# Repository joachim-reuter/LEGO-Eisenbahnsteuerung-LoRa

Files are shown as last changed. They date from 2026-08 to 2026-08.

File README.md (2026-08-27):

# LEGO-Eisenbahnsteuerung mit ESP32 und LoRa
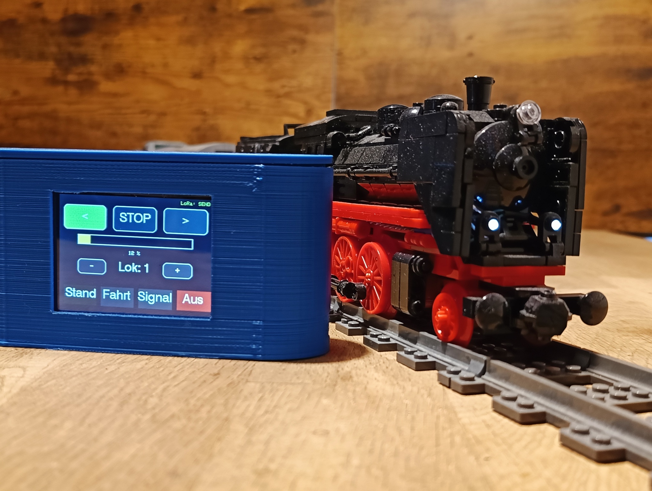
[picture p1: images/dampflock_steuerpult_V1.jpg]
LEGO-Eisenbahnanlage

Drahtlose Steuerung einer LEGO-Eisenbahn mit ESP32, LoRa, TFT-Touchdisplay, Motortreiber und Sound.

## Projektübersicht

                         LEGO-EISENBAHN
                               │
              ┌────────────────┴────────────────┐
              │                                 │
              ▼                                 ▼
       LOKSTEUERUNG                       WEICHENSTEUERUNG
              │                                 │
        TFT Touchdisplay                  TFT Touchdisplay
              │                                 │
              ▼                                 ▼
        LoRa Sender                        LoRa Sender
              │                                 │
              │ 868,1 MHz                     │ 868,3 MHz
              ▼                                 ▼
        LoRa Empfänger                    LoRa Empfänger
              │                                 │
        ┌─────┴─────┐                         │
        │           │                         │
      DRV8833   DFPlayer                    DRV8833
        │           │                         │
        ▼           ▼                         ▼
    LEGO-Motor    Sound                   Weichenmotor

Das Projekt besteht aus zwei getrennten Steuerungsbereichen:

- Loksteuerung
- Weichensteuerung

Die Bedienung erfolgt über TFT-Touchdisplays. Die Steuerbefehle werden drahtlos über LoRa an die jeweiligen Empfänger übertragen.

1. Loksteuerung

Die Lok wird über ein TFT-Touchdisplay gesteuert.

Funktionen
Vorwärts
Stop
Rückwärts
Geschwindigkeit 0–100 %
Auswahl der Lok-ID
Soundsteuerung
LoRa-Übertragung
automatische zyklische Übertragung
Failsafe beim Empfänger

Richtungen

0 = STOP
1 = VORWÄRTS
2 = RÜCKWÄRTS

Geschwindigkeit

Die Geschwindigkeit wird auf dem Touchdisplay von 0–100 %

eingestellt.

Für die Übertragung wird dieser Wert auf den PWM-Bereich 0–255

umgerechnet.

2. Soundsteuerung

Die Loksteuerung besitzt vier Soundmodi:

0 = SOUND_OFF
1 = SOUND_STAND
2 = SOUND_DRIVE
3 = SOUND_SIGNAL

Der Empfänger verwendet einen DFPlayer Mini zur Wiedergabe der Sounds.

Die Dateien liegen im Ordner:

/01/

mit:

001.mp3 = Fahrt
002.mp3 = Stand
003.mp3 = Signal

3. Lok-ID

Über die Touchoberfläche kann die aktive Lok ausgewählt werden.

Die Lok-ID wird zusammen mit den Steuerdaten über LoRa übertragen.

Im Empfänger wird festgelegt, auf welche Lok-ID der Empfänger reagiert.

Beispiel:
#define MY_LOK_ID 1
Damit können mehrere Lokempfänger mit unterschiedlichen IDs betrieben werden.

4. LoRa-Daten der Loksteuerung

Der Lok-Sender überträgt vier Bytes:

Byte 1   Lok-ID
Byte 2   Richtung
Byte 3   Geschwindigkeit
Byte 4   Sound-Modus

Beispiel:

Lok 1
Richtung vorwärts
Geschwindigkeit 50 %
Sound Fahrt

wird als entsprechende Bytefolge übertragen.

Die Geschwindigkeit wird vor der Übertragung von 0–100 % auf 0–255 umgesetzt.

5. Lok-Empfänger

Der Lok-Empfänger verarbeitet die LoRa-Steuerdaten und steuert damit den LEGO-Motor.

Verwendet werden:

ESP32
LoRa-Modul
DRV8833 Motortreiber
DFPlayer Mini
Motortreiber

Der DRV8833 wird für die Richtungs- und Geschwindigkeitssteuerung verwendet.

Die Geschwindigkeit wird über PWM gesteuert.

PWM-Frequenz: 20 kHz
Auflösung:    8 Bit

6. Failsafe

Der Lok-Empfänger besitzt eine Sicherheitsfunktion.

Wenn länger als

800 ms

kein gültiges Steuerpaket empfangen wird, wird:

der Motor gestoppt
der Motortreiber deaktiviert
der Sound ausgeschaltet

Damit wird verhindert, dass eine Lok bei einem Ausfall der Funkverbindung unkontrolliert weiterfährt.

7. Weichensteuerung

Die Weichen werden ebenfalls über ein TFT-Touchdisplay gesteuert.

Über das Display kann zwischen zwei Weichen umgeschaltet werden:

Weiche 1
Weiche 2

Für die ausgewählte Weiche kann anschließend gewählt werden:

Gerade
Abzweig

8. Weichensteuerung über LoRa

Die Weichensteuerung verwendet eine eigene LoRa-Frequenz:

868,3 MHz

Der Sender überträgt:

Byte 1   Weichen-ID
Byte 2   Schaltbefehl

Die Befehle sind:

1 = Gerade
2 = Abzweig

9. Weichen-Empfänger

Der Weichen-Empfänger steuert den Weichenmotor über einen DRV8833.

Zum Schalten wird ein kurzer Motorimpuls verwendet.

PWM:          80
Impulsdauer:  400 ms

Nach dem Impuls wird der Motor wieder abgeschaltet.

Dadurch wird der Weichenantrieb nicht dauerhaft bestromt.

10. Speicherung des Weichenzustands

Der zuletzt bekannte Zustand der Weiche wird im EEPROM des ESP32 gespeichert.

Damit bleibt der Zustand auch nach einem Neustart erhalten.

Gespeichert wird:

1 = GERADE
2 = ABZWEIG

Beim Einschalten wird der gespeicherte Zustand aus dem EEPROM gelesen.

Ist kein gültiger Zustand gespeichert, wird als Standard verwendet:

GERADE

11. Hardware
Lok-Sender:
ESP32
TFT-Touchdisplay
LoRa-Modul
Lok-Empfänger:
ESP32
LoRa-Modul
DRV8833
LEGO-Motor
DFPlayer Mini
Lautsprecher
Weichen-Sender:
ESP32
TFT-Touchdisplay
LoRa-Modul
Weichen-Empfänger:
ESP32
LoRa-Modul
DRV8833
Weichenmotor
EEPROM des ESP32

12. LoRa-Anschluss

Für die LoRa-Module werden folgende SPI-Pins verwendet:

ESP32	Funktion
GPIO 18	SCK
GPIO 19	MISO
GPIO 23	MOSI
GPIO 5	SS / CS
GPIO 17	RESET
GPIO 26	DIO0

13. Motorsteuerung

Die Motorsteuerung der Lok verwendet:

ESP32	Funktion
GPIO 25	IN1
GPIO 33	IN2
GPIO 32	ENA
GPIO 27	STBY

Der DRV8833 ermöglicht:

Vorwärtsfahrt
Rückwärtsfahrt
Stop
Geschwindigkeitsregelung über PWM

14. DFPlayer Mini

Der DFPlayer Mini wird über eine serielle Schnittstelle angeschlossen.

GPIO 16 = RX
GPIO 4  = TX

Der Player wird mit

9600 Baud

betrieben.

Die Sounddateien werden über Ordner und Dateinummer angesprochen.

15. TFT-Touchdisplay

Die Steuerung verwendet ein TFT-Touchdisplay mit der Bibliothek:

TFT_eSPI

Die Touchkalibrierung wird im jeweiligen Sender-Sketch gespeichert.

Das Display stellt die wichtigsten Funktionen direkt als Touchflächen bereit.

16. Verwendete Software und Bibliotheken
Lok-Sender:
TFT_eSPI
SPI
LoRa
Lok-Empfänger:
SPI
LoRa
DFRobotDFPlayerMini
Weichen-Sender:
TFT_eSPI
SPI
LoRa
Weichen-Empfänger:
SPI
LoRa
EEPROM

17. Dateien im Repository
Loksteuerung/
├── _LoRaLock_Sender.ino
└── _LoRaLock_Empfänger.ino

Weichensteuerung/
├── _LoRaWeiche_Sender.ino
└── _LoRaWeiche_Empfänger.ino

18. Aufbau

Das Projekt ist modular aufgebaut.

Die Bedienung und die eigentliche Steuerung sind voneinander getrennt:

Touchscreen
    │
    ▼
LoRa-Sender
    │
    │ Funk
    ▼
LoRa-Empfänger
    │
    ▼
Motortreiber
    │
    ▼
Motor

Dadurch können Steuerung und Fahrzeuge räumlich voneinander getrennt betrieben werden.

19. Mehrere Loks

Durch die Verwendung einer Lok-ID kann ein Empfänger gezielt auf seine eigene Lok-ID reagieren.

Beispiel:

Lok 1 → MY_LOK_ID 1
Lok 2 → MY_LOK_ID 2
Lok 3 → MY_LOK_ID 3

Der Sender kann die gewünschte Lok über die Touchoberfläche auswählen.

Das Konzept ermöglicht damit eine spätere Erweiterung auf mehrere Loks.

20. Mehrere Weichen

Auch die Weichen werden über eine ID angesprochen:

Weiche 1
Weiche 2

Das gleiche Prinzip kann später auf weitere Weichen erweitert werden.

21. Sicherheit

Die Loksteuerung verwendet einen Kommunikations-Timeout.

Wird keine gültige Steuerung mehr empfangen, wird die Lok automatisch gestoppt.

Bei der Weichensteuerung wird der Motor nur für die definierte Impulsdauer aktiviert.

22. Projektstatus

Das Projekt befindet sich in aktiver Weiterentwicklung.

Die hier veröffentlichten Sketches entsprechen dem aktuell funktionierenden Entwicklungsstand.

Autor

Joachim Reuter

Dieses Projekt entstand als privates Elektronik- und Modellbahnprojekt mit ESP32 und LoRa.

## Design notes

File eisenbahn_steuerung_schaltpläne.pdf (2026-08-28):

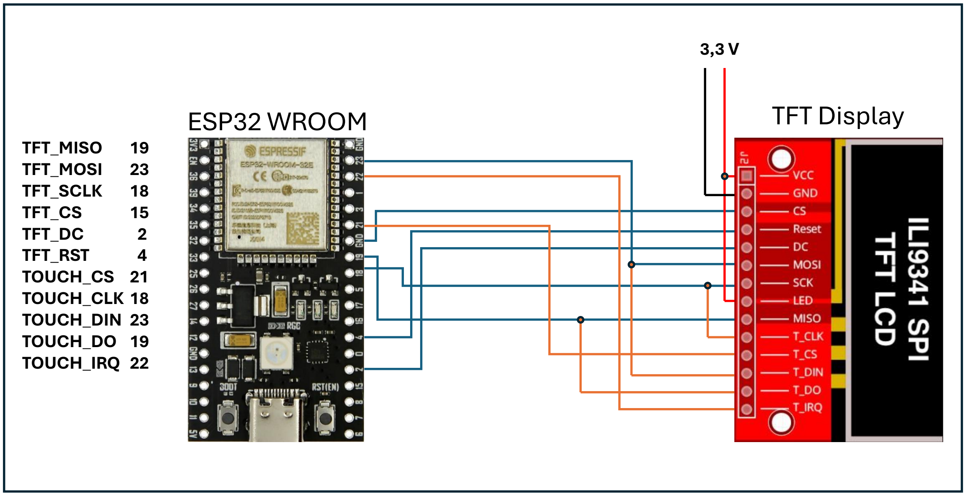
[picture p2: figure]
TFT_MISO; TFT_MOSI; TFT_SCLK; TFT_CS; TFT_DC; TFT_RST; 4 TOUCH_CS 21 TOUCH_CLK 18 TOUCH_DIN 23 TOUCH_DO 19 TOUCH_IRQ 22; ESP32 WROOM; TFT Display

3,3 V

LORA_SCK 18
LORA_MISO 19
LORA_MOSI 23
LORA_SS 5
LORA_RST 17
LORA_DIO0 26

## ESP32 WROOM

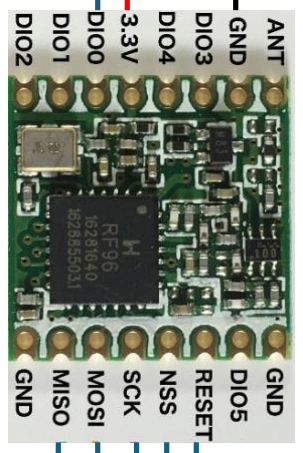
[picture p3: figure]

## LoRa SX1278

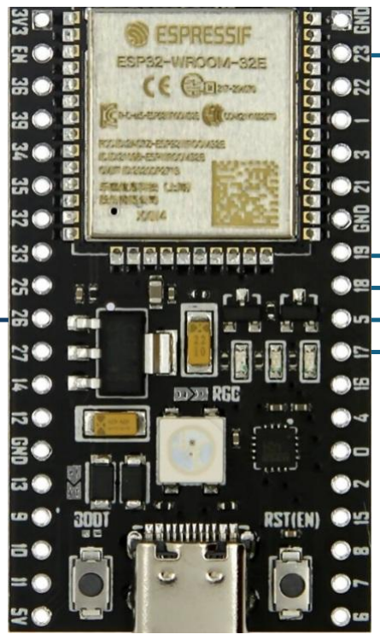
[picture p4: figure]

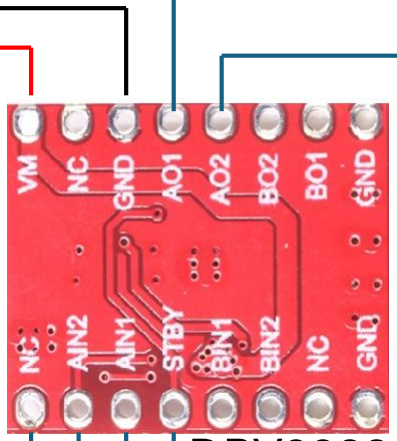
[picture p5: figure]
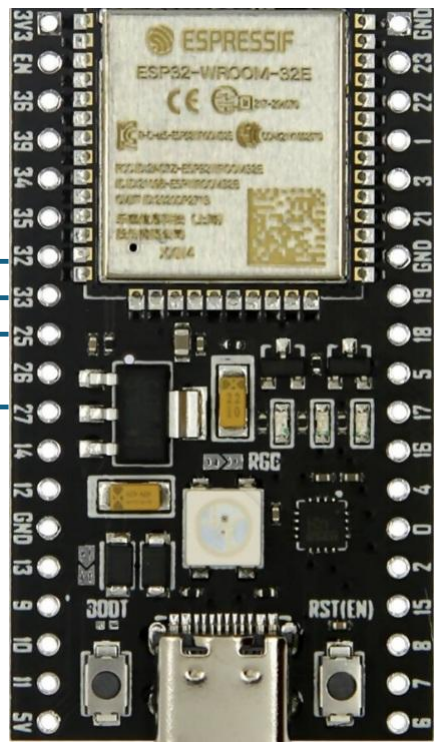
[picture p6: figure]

## DRV8833

## ESP32 WROOM

Antriebsmotor

Scheinwerfer/Rücklicht
7,4 V

IN1 25
IN2 33
ENA 32
STBY 27

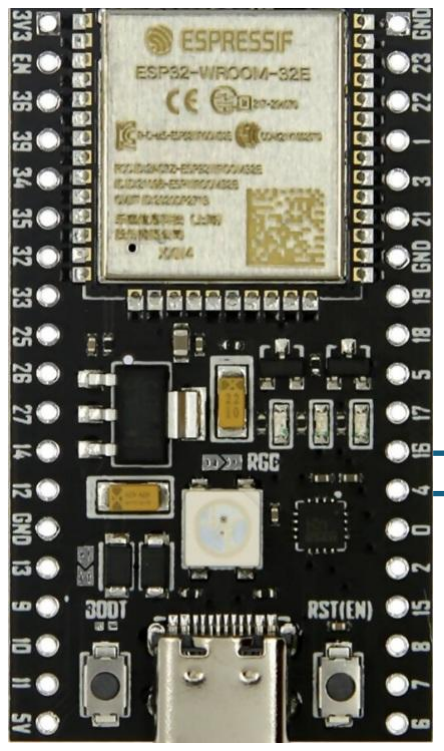
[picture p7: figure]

3,3 V

DF_RX 16
DF_TX 4

## ESP32 WROOM

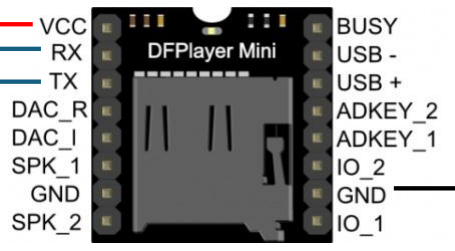
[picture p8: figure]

## DFPlayer

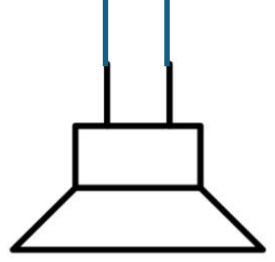
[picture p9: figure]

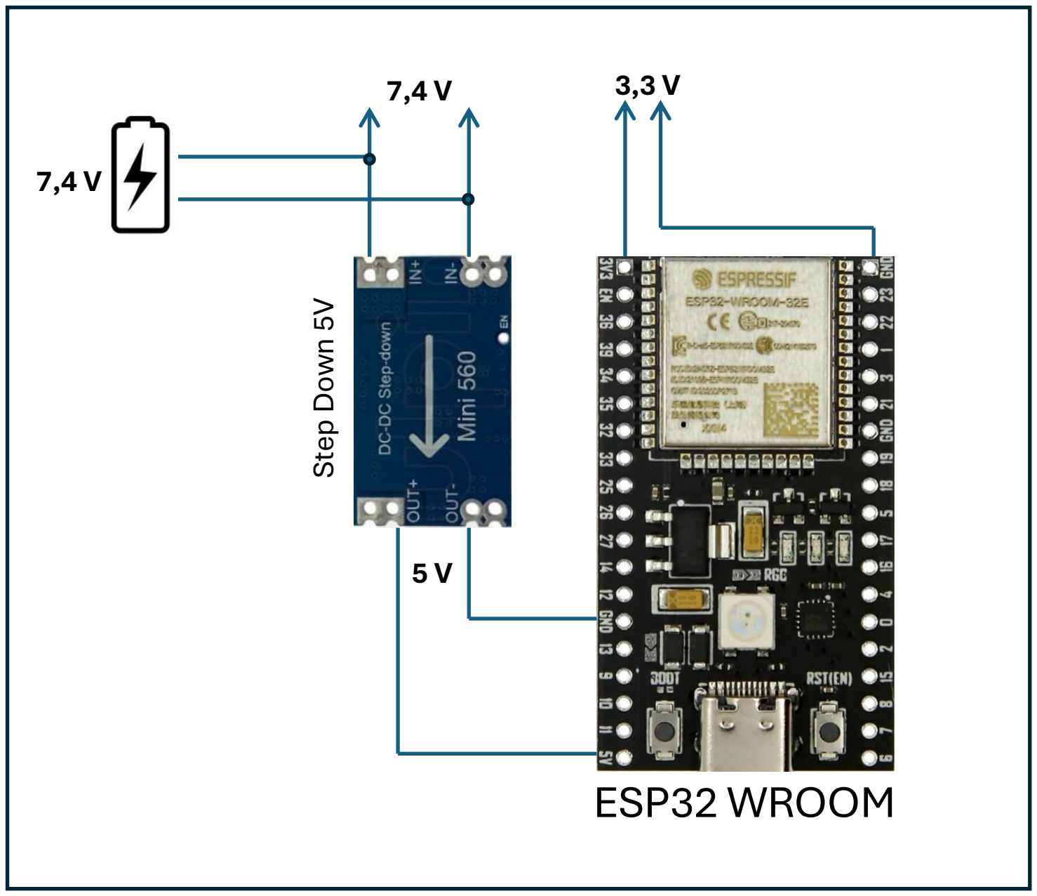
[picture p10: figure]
ESP32 WROOM; Step Down 5V

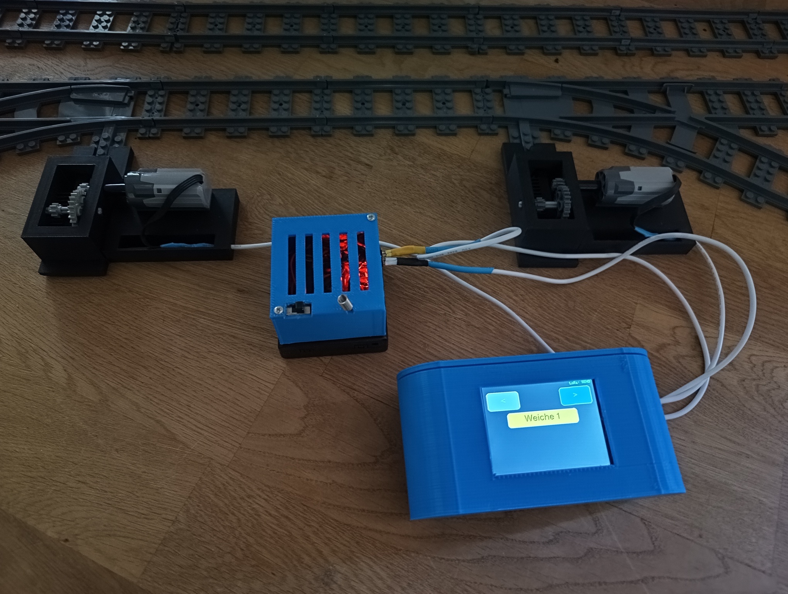
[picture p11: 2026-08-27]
images/weiche_V1.jpg

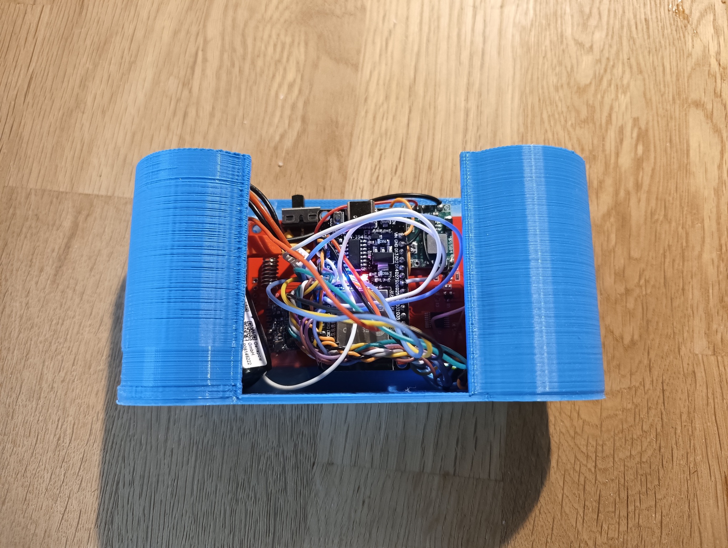
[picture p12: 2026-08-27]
images/pult_innen_V1.jpg

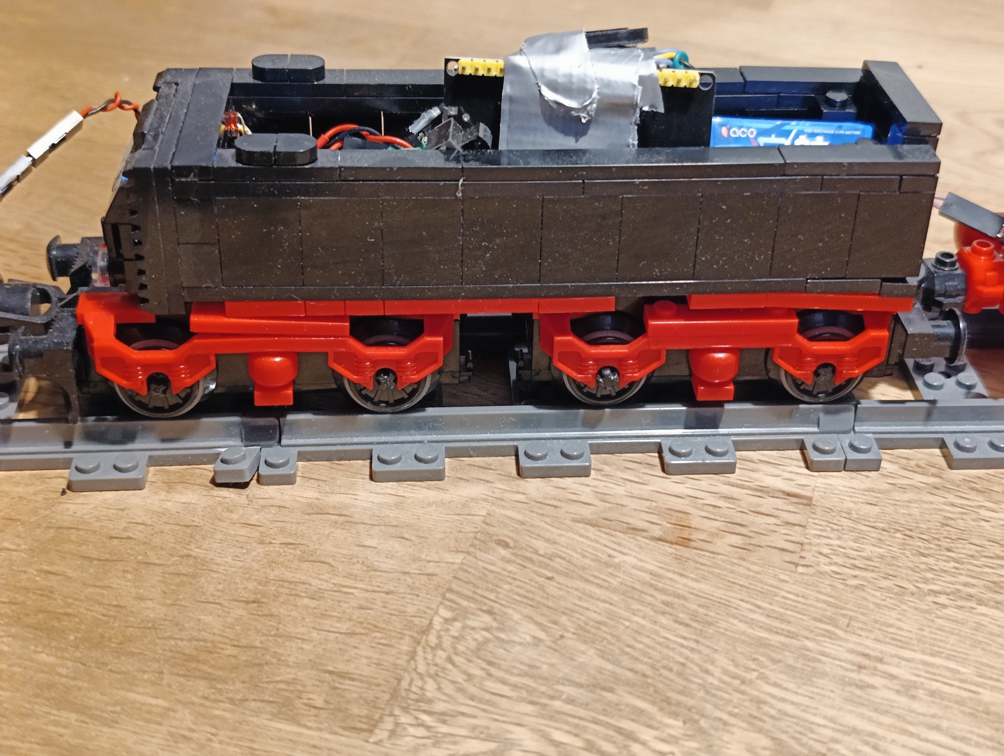
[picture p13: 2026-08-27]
images/tender_V1.jpg

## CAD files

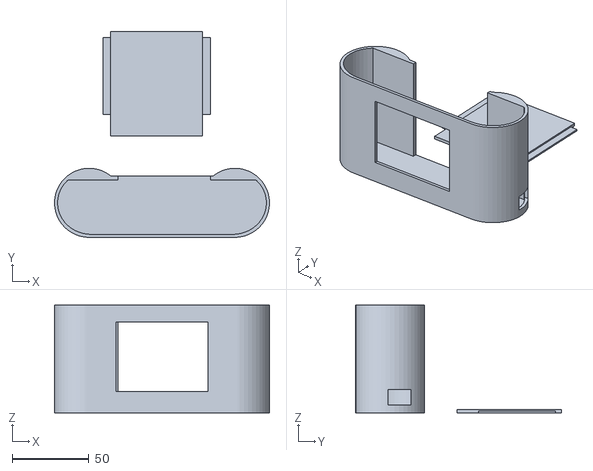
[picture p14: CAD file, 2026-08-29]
3d_print/Bahn_Controler_V4.stl
140.0 x 134.0 x 70.0

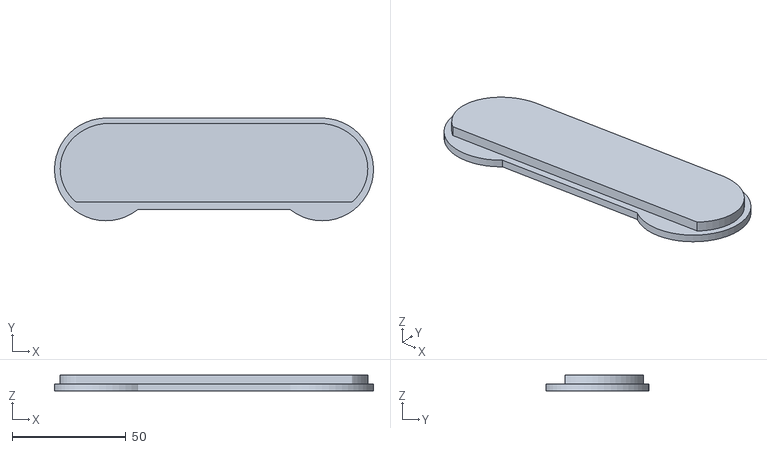
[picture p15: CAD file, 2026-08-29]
3d_print/Bahn_Deckel_V1.stl
140.0 x 45.0 x 7.00

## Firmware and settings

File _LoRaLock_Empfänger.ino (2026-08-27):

#include <SPI.h>
#include <LoRa.h>
#include <DFRobotDFPlayerMini.h>

// ================= LOK =================
#define MY_LOK_ID 1

// ================= LoRa =================
#define LORA_SCK   18
#define LORA_MISO  19
#define LORA_MOSI  23
#define LORA_SS     5
#define LORA_RST   17
#define LORA_DIO0  26

// ================= DRV8833 =================
const int IN1  = 25;
const int IN2  = 33;
const int ENA  = 32;
const int STBY = 27;

// ================= PWM =================
#define PWM_CH   0
#define PWM_FREQ 20000
#define PWM_RES  8

// ================= DFPLAYER =================
#define DF_RX 16
#define DF_TX 4

HardwareSerial dfSerial(1);
DFRobotDFPlayerMini dfplayer;
bool soundReady = false;

// ================= SYSTEM =================
bool systemReady = false;   // <-- HIER

// ================= SOUND =================
enum SoundMode {
  SOUND_OFF = 0,
  SOUND_STAND = 1,
  SOUND_DRIVE = 2,
  SOUND_SIGNAL = 3
};

// Ordner 01
#define FOLDER_SOUND 1

#define FILE_DRIVE  1   // 001.mp3
#define FILE_STAND  2   // 002.mp3
#define FILE_SIGNAL 3   // 003.mp3

SoundMode currentSound = SOUND_OFF;

// ================= FAILSAFE =================
unsigned long lastPacketTime = 0;
const unsigned long TIMEOUT_MS = 800;

// =================================================

void motorStop() {
  digitalWrite(IN1, LOW);
  digitalWrite(IN2, LOW);
  ledcWrite(PWM_CH, 0);
  digitalWrite(STBY, LOW);
}

void motorSet(uint8_t dir, uint8_t spd) {
  if (dir == 0 || spd == 0) {
    motorStop();
    return;
  }

  digitalWrite(STBY, HIGH);

  digitalWrite(IN1, dir == 1);
  digitalWrite(IN2, dir == 2);

  ledcWrite(PWM_CH, spd);
}

// =================================================

void setSound(uint8_t cmd) {
  if (!soundReady) return;

  // Signal darf immer
  if (cmd == currentSound && cmd != SOUND_SIGNAL) return;

  dfplayer.stop();
  delay(80);

  switch (cmd) {
    case SOUND_OFF:
      // nichts
      break;

    case SOUND_STAND:
      dfplayer.playFolder(FOLDER_SOUND, FILE_STAND);
      break;

    case SOUND_DRIVE:
      dfplayer.playFolder(FOLDER_SOUND, FILE_DRIVE);
      break;

    case SOUND_SIGNAL:
      dfplayer.playFolder(FOLDER_SOUND, FILE_SIGNAL);
      return;   // kein Statuswechsel
  }

  currentSound = (SoundMode)cmd;
}



// =================================================

void setup() {
  Serial.begin(115200);
  delay(500);

  // Motor
  pinMode(IN1, OUTPUT);
  pinMode(IN2, OUTPUT);
  pinMode(STBY, OUTPUT);
  digitalWrite(STBY, LOW);

  ledcSetup(PWM_CH, PWM_FREQ, PWM_RES);
  ledcAttachPin(ENA, PWM_CH);

  motorStop();

  // DFPlayer
  dfSerial.begin(9600, SERIAL_8N1, DF_RX, DF_TX);
  delay(2000);

  if (dfplayer.begin(dfSerial)) {
    delay(500);
    dfplayer.outputDevice(DFPLAYER_DEVICE_SD);
    delay(200);
    dfplayer.volume(30);
    dfplayer.stop();
    soundReady = true;
    Serial.println("DFPlayer OK");
  } else {
    Serial.println("DFPlayer FEHLER");
  }

  // LoRa
  SPI.begin(LORA_SCK, LORA_MISO, LORA_MOSI, LORA_SS);
  LoRa.setPins(LORA_SS, LORA_RST, LORA_DIO0);

  if (!LoRa.begin(868E6)) {
    Serial.println("LoRa Fehler");
    while (1);
  }

  Serial.println("Empfaenger bereit");
  motorStop();
  setSound(SOUND_OFF);
  lastPacketTime = millis();

}

// =================================================

void loop() {
  int size = LoRa.parsePacket();
  if (size == 4) {
    uint8_t lok  = LoRa.read();
    uint8_t dir  = LoRa.read();
    uint8_t spd  = LoRa.read();
    uint8_t snd  = LoRa.read();

    if (lok == MY_LOK_ID) {
      lastPacketTime = millis();
      systemReady = true;
      motorSet(dir, spd);
      setSound(snd);

      Serial.printf(
        "RX Lok:%d Dir:%d Speed:%d Sound:%d\n",
        lok, dir, spd, snd
      );
    }
  }

  // FAILSAFE
  if (millis() - lastPacketTime > TIMEOUT_MS) {
    motorStop();
    setSound(SOUND_OFF);
  }
  if (!systemReady) {
    motorStop();
    setSound(SOUND_OFF);
    return;
  }

}

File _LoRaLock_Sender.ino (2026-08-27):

#include <TFT_eSPI.h>
#include <SPI.h>
#include <LoRa.h>

// ================= TFT =================
TFT_eSPI tft = TFT_eSPI();
uint16_t calData[5] = { 526, 3172, 449, 3087, 1 };

// ================= LoRa Pins =================
#define LORA_SCK   18
#define LORA_MISO  19
#define LORA_MOSI  23
#define LORA_SS     5
#define LORA_RST   17
#define LORA_DIO0  26

// ================= Steuerdaten =================
uint8_t lokID     = 1;   // aktive Lok
uint8_t direction = 0;   // 0=STOP,1=VOR,2=ZURUECK
uint8_t speed     = 0;   // 0–100 % (UI)

enum SoundMode {
  SOUND_OFF    = 0,
  SOUND_STAND  = 1,
  SOUND_DRIVE  = 2,
  SOUND_SIGNAL = 3
};

uint8_t soundMode = SOUND_OFF;


// ================= Timing =================
unsigned long lastSend = 0;
const unsigned long SEND_INTERVAL = 300;

// ================= UI Geometrie =================
#define BTN_W 90
#define BTN_H 50
#define BTN_Y 20

#define BTN_VOR_X     10
#define BTN_STOP_X  115
#define BTN_BACK_X  220

#define SLIDER_X 40
#define SLIDER_Y 80
#define SLIDER_W 240
#define SLIDER_H 20

#define LOK_Y 130
#define LOK_BTN_W 60
#define LOK_BTN_H 30
#define LOK_MINUS_X 40
#define LOK_PLUS_X  220

// #define BTN_S_X  200
#define BTN_S_Y  185
#define BTN_S_W   70
#define BTN_S_H    40

#define BTN_S1_X   10   // Fahrt
#define BTN_S2_X   90   // Stand
#define BTN_S3_X  170   // Signal
#define BTN_S4_X  250   // Aus




// =================================================

bool inRect(int x, int y, int rx, int ry, int rw, int rh) {
  return (x >= rx && x <= rx + rw && y >= ry && y <= ry + rh);
}

enum LoRaStatus {
  LORA_INIT,
  LORA_SEND,
  LORA_ERROR
};

LoRaStatus loraStatus = LORA_INIT;
unsigned long loraStatusTime = 0;



void drawButton(int x, int y, int w, int h, const char* label, bool active, uint16_t color) {
  uint16_t fill = active ? color : TFT_DARKGREY;
  tft.fillRoundRect(x, y, w, h, 8, fill);
  tft.drawRoundRect(x, y, w, h, 8, TFT_WHITE);
  tft.setTextDatum(MC_DATUM);
  tft.setTextColor(TFT_WHITE);
  tft.drawString(label, x + w / 2, y + h / 2, 4);
}

void drawSoundButtons() {

  uint16_t c1 = (soundMode == SOUND_DRIVE)  ? TFT_GREEN  : TFT_DARKGREEN;
  uint16_t c2 = (soundMode == SOUND_STAND)  ? TFT_BROWN  : TFT_DARKGREY;
  uint16_t c3 = (soundMode == SOUND_SIGNAL) ? TFT_ORANGE : TFT_DARKGREY;
  uint16_t c4 = (soundMode == SOUND_OFF)    ? TFT_RED    : TFT_DARKGREY;

  tft.fillRect(BTN_S1_X, BTN_S_Y, BTN_S_W, BTN_S_H, c1);
  tft.drawString("            Stand", BTN_S1_X + 6, BTN_S_Y + 18, 4);

  tft.fillRect(BTN_S2_X, BTN_S_Y, BTN_S_W, BTN_S_H, c2);
  tft.drawString("           Fahrt", BTN_S2_X + 6, BTN_S_Y + 18, 4);

  tft.fillRect(BTN_S3_X, BTN_S_Y, BTN_S_W, BTN_S_H, c3);
  tft.drawString("            Signal", BTN_S3_X + 4, BTN_S_Y + 18, 4);

  tft.fillRect(BTN_S4_X, BTN_S_Y, BTN_S_W, BTN_S_H, c4);
  tft.drawString("      Aus", BTN_S4_X + 18, BTN_S_Y + 18, 4);
}





void drawSlider() {
  tft.drawRect(SLIDER_X, SLIDER_Y, SLIDER_W, SLIDER_H, TFT_WHITE);
  tft.fillRect(SLIDER_X + 1, SLIDER_Y + 1, SLIDER_W - 2, SLIDER_H - 2, TFT_BLACK);

  int fillW = map(speed, 0, 100, 0, SLIDER_W);
  if (fillW > 0) {
    tft.fillRect(SLIDER_X + 1, SLIDER_Y + 1, fillW - 2, SLIDER_H - 2, TFT_YELLOW);
  }

  tft.setTextDatum(TC_DATUM);
  tft.drawString(String(speed) + " %", SLIDER_X + SLIDER_W / 2, SLIDER_Y + 30);
}

void drawLokSelector() {
  tft.fillRect(0, LOK_Y - 10, 320, 50, TFT_BLACK);

  drawButton(LOK_MINUS_X, LOK_Y, LOK_BTN_W, LOK_BTN_H, "-", false, TFT_DARKGREY);
  drawButton(LOK_PLUS_X,  LOK_Y, LOK_BTN_W, LOK_BTN_H, "+", false, TFT_DARKGREY);

  tft.setTextDatum(MC_DATUM);
  tft.drawString("Lok: " + String(lokID), 160, LOK_Y + 15,  4);
}

void drawUI() {
  tft.fillScreen(TFT_BLACK);

  drawButton(BTN_VOR_X,  BTN_Y, BTN_W, BTN_H, "<",     direction == 1, TFT_GREEN);
  drawButton(BTN_STOP_X, BTN_Y, BTN_W, BTN_H, "STOP",    direction == 0, TFT_RED);
  drawButton(BTN_BACK_X, BTN_Y, BTN_W, BTN_H, ">", direction == 2, TFT_BLUE);

  //tft.drawString("    Geschwindigkeit", SLIDER_X, SLIDER_Y - 30);
  drawSlider();
  drawLokSelector();
  drawSoundButtons();
  drawLoRaStatus();

}

// ================= LoRa =================
void sendLoRa() {
  uint8_t spdByte = map(speed, 0, 100, 0, 255);

  LoRa.beginPacket();
  LoRa.write(lokID);
  LoRa.write(direction);
  LoRa.write(spdByte);
  LoRa.write(soundMode);
  LoRa.endPacket();

  Serial.printf("TX -> Lok:%d Dir:%d Speed:%d\n", lokID, direction, spdByte);

  loraStatus = LORA_SEND;
  loraStatusTime = millis();
  drawLoRaStatus(); 


}

void drawLoRaStatus() {
  uint16_t color;
  String text;

  switch (loraStatus) {
    case LORA_INIT:
      color = TFT_YELLOW;
      text = "LoRa: AKTIV";
      break;
    case LORA_SEND:
      color = TFT_GREEN;
      text = "LoRa: SEND";
      break;
    case LORA_ERROR:
      color = TFT_RED;
      text = "LoRa: ERROR";
      break;
  }

  // Bereich löschen
  tft.fillRect(180, 0, 140, 20, TFT_BLACK);

  tft.setTextDatum(TR_DATUM);
  tft.setTextColor(color, TFT_BLACK);
  tft.drawString(text, 315, 5);
}








// =================================================

void setup() {
  Serial.begin(115200);

  // TFT
  tft.init();
  tft.setRotation(3);
  tft.setTouch(calData);
  tft.setTextColor(TFT_WHITE, TFT_BLACK);

  // SPI & LoRa
  SPI.begin(LORA_SCK, LORA_MISO, LORA_MOSI, LORA_SS);
  LoRa.setPins(LORA_SS, LORA_RST, LORA_DIO0);
  
  if (!LoRa.begin(868100000)) {
    Serial.println("LoRa Fehler!");
    loraStatus = LORA_ERROR;
  } else {
    loraStatus = LORA_INIT;
  }


  drawUI();
  Serial.println("Sender bereit");
}
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
